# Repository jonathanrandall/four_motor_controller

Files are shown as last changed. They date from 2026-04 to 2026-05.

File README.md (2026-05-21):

# NOTE

This was originally done in kicad 9.0 and updated to kicad 10.0. Need to check the symbol for the NMOS transistor against the data sheet for the transistor in the bom file

# four_motor_controller

A 4-layer PCB motor controller for robotics applications. Drives 4 DC motors with encoder feedback using an ESP32-S3 microcontroller, 
Inlcudes:
* 4× VNH7040AYTR high-current motor drivers, which is rated for 35A, but the current is limited by the board and not the motor driver. I'm using 2oz copper on the outer layers and 1oz copper on the inner layers, so this should provide ~12A continuous current on each motor driver; and a
* MCP23017 I2C GPIO expander for direction control.

The design files are for KiCad 10.0.

The ROS2 control code used in the video is at https://github.com/jonathanrandall/new_pcb_robot

## Repository Contents

```
hardware/                   # KiCad schematic, PCB layout, and project files
  symbols/                  # Custom KiCad symbol and footprint for VNH7040AYTR
docs_and_outputs/           # BOM (JLCPCB format), Gerbers (zip), PINMAP, and datasheets
firmware/esp32_bridge/      # PlatformIO firmware project (Arduino framework, C++17)
  src/                      # main.cpp, Motor, PIDController, QuadratureEncoder,
                            #   RobotController, Mcp23017Bus, WebDashboard, PanTiltController
  include/                  # Header files
  platformio.ini            # Build configuration
```

## Important Notes

**The BOM and PINMAP in `docs_and_outputs/` may be out of date.** Always cross-reference against the schematic and PCB files before ordering parts or assembling hardware.

**The custom VNH7040AYTR symbol/footprint** (`hardware/symbols/`) must be added to your KiCad library if opening the project on a new machine.

**The firmware has not been validated on hardware.** It compiles and is provided as a starting point.

**WiFi credentials are not included.** Before building the firmware, set your SSID and password in `firmware/esp32_bridge/src/main.cpp`.

## Building the Firmware

Requires [PlatformIO](https://platformio.org/). All commands run from `firmware/esp32_bridge/`.

```bash
# Build
pio run

# Flash (USB-C, use BOOT mode if required)
pio run --target upload

# Monitor serial output (115200 baud)
pio device monitor
```

## Contributing

Contributions are welcome. If you have your own motor controller design or variant you would like to share, please add it in its own directory rather than modifying the existing files. Pull requests with bug fixes or improvements to the existing design are welcome.

## Disclaimer

This hardware design is provided as-is, with no warranty of any kind. Anyone who uses, manufactures, or builds upon these files does so entirely at their own risk. The author accepts no responsibility for any damage to property, equipment, or persons resulting from the use of this design. Always verify the design independently before fabrication or use in any application.

## Licence

The hardware design files in this repository are licensed under the
CERN Open Hardware Licence Version 2 - Permissive (CERN-OHL-P-2.0).

See the `LICENSE` file for the full licence text.

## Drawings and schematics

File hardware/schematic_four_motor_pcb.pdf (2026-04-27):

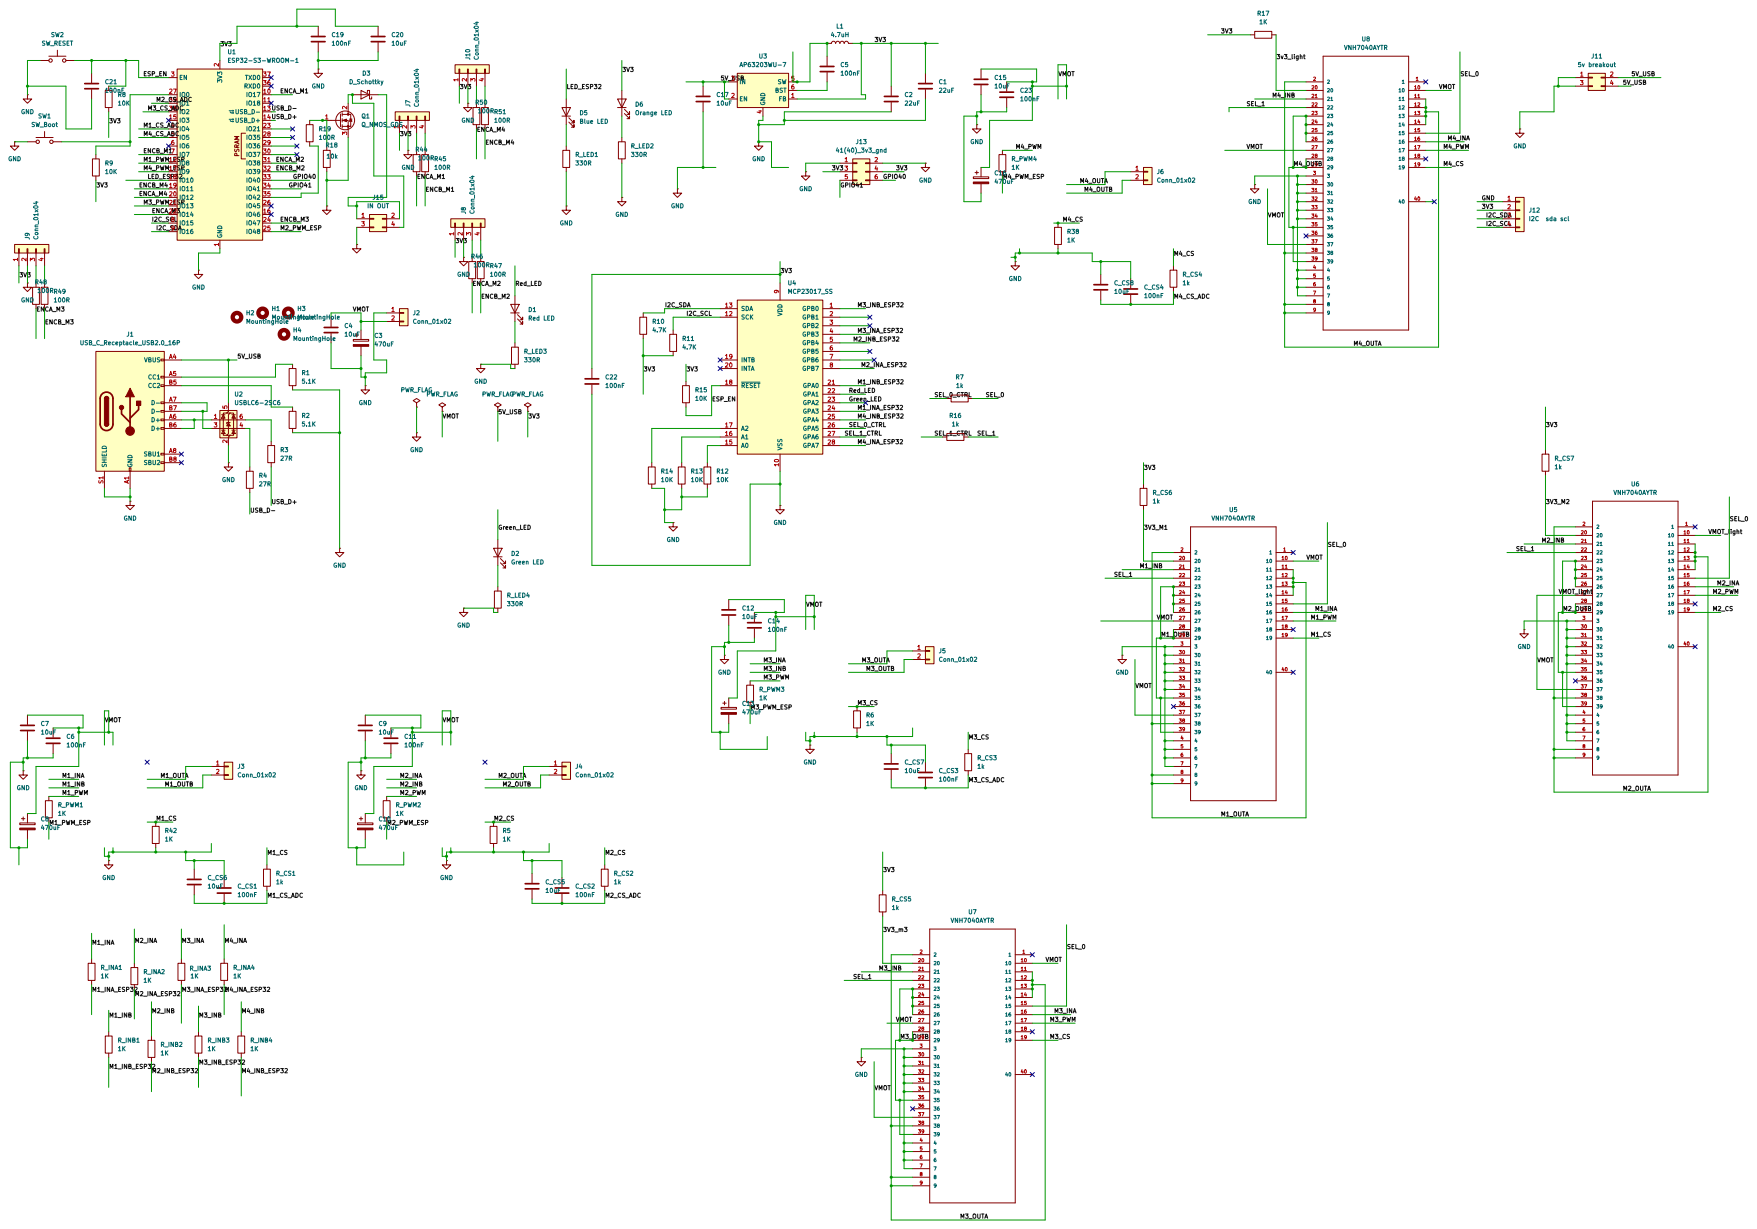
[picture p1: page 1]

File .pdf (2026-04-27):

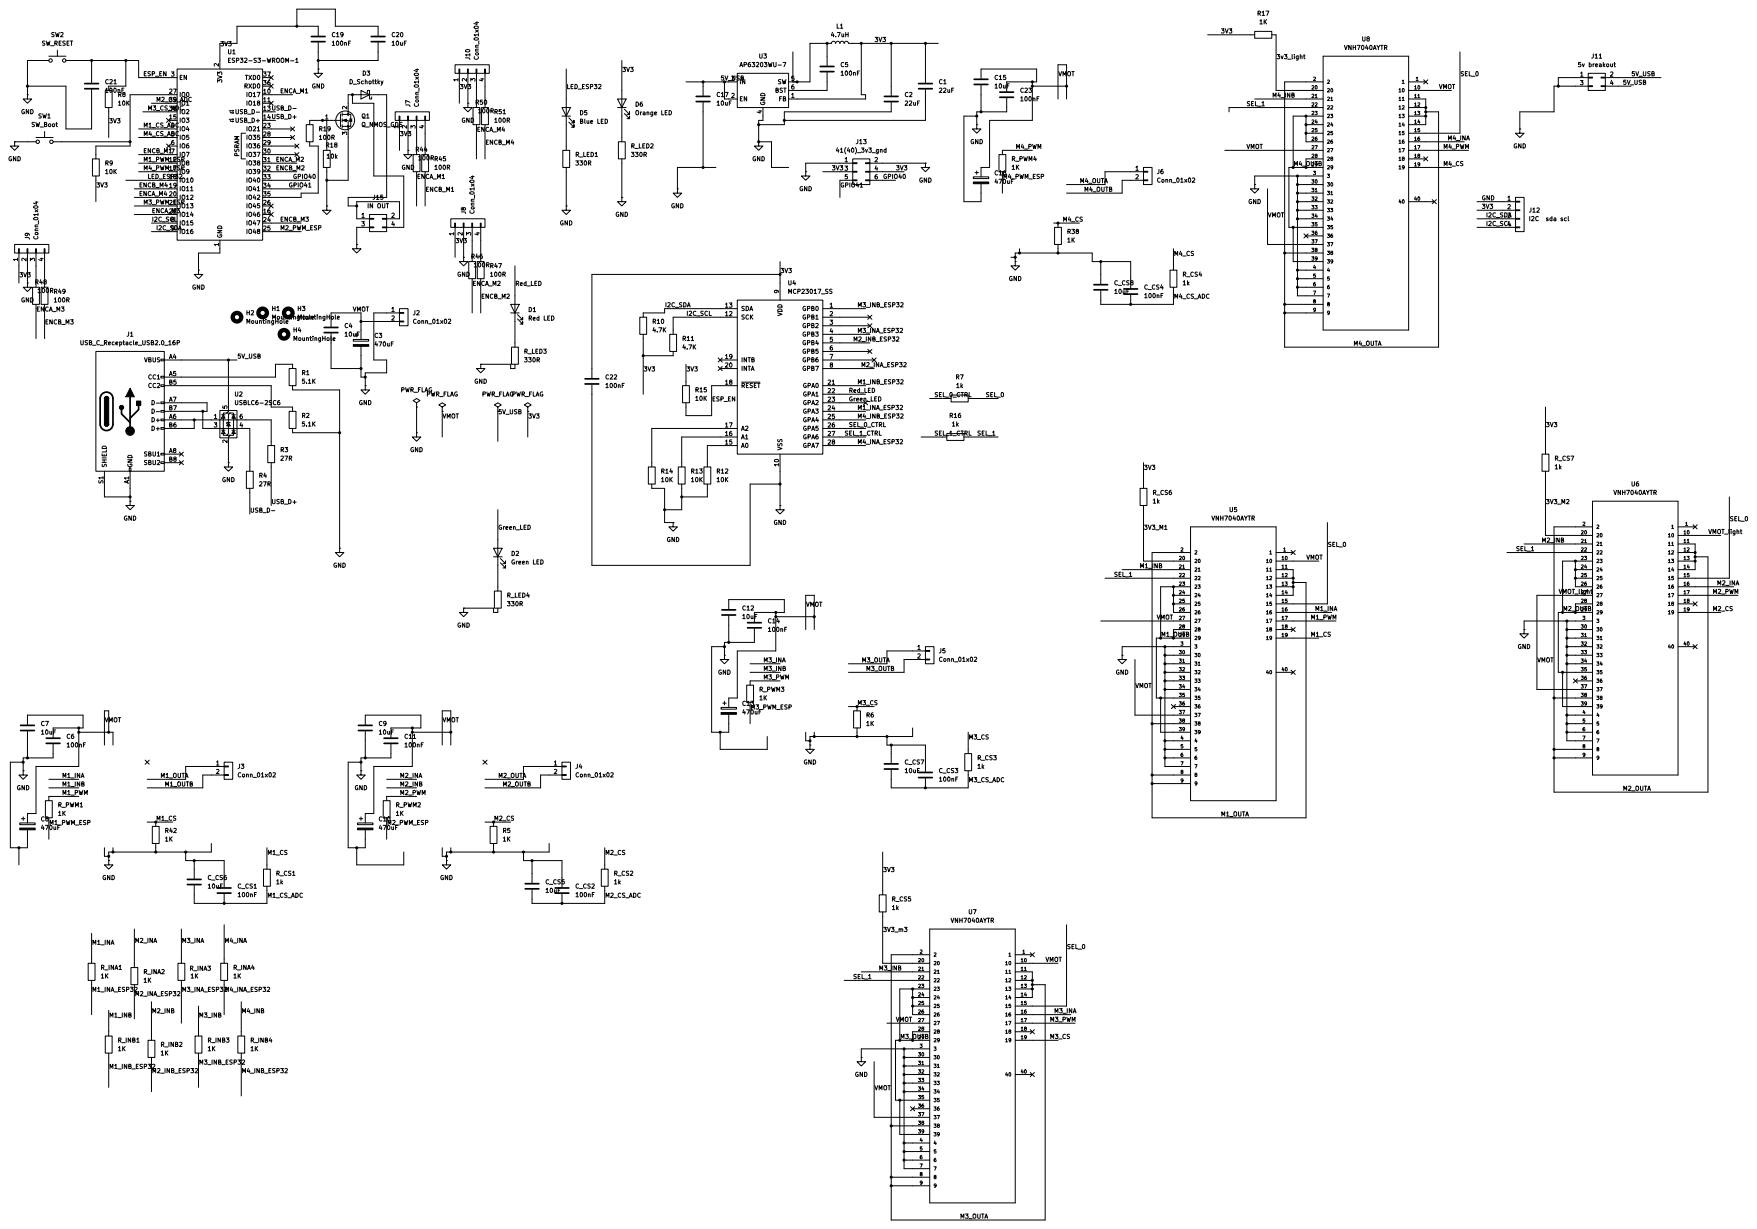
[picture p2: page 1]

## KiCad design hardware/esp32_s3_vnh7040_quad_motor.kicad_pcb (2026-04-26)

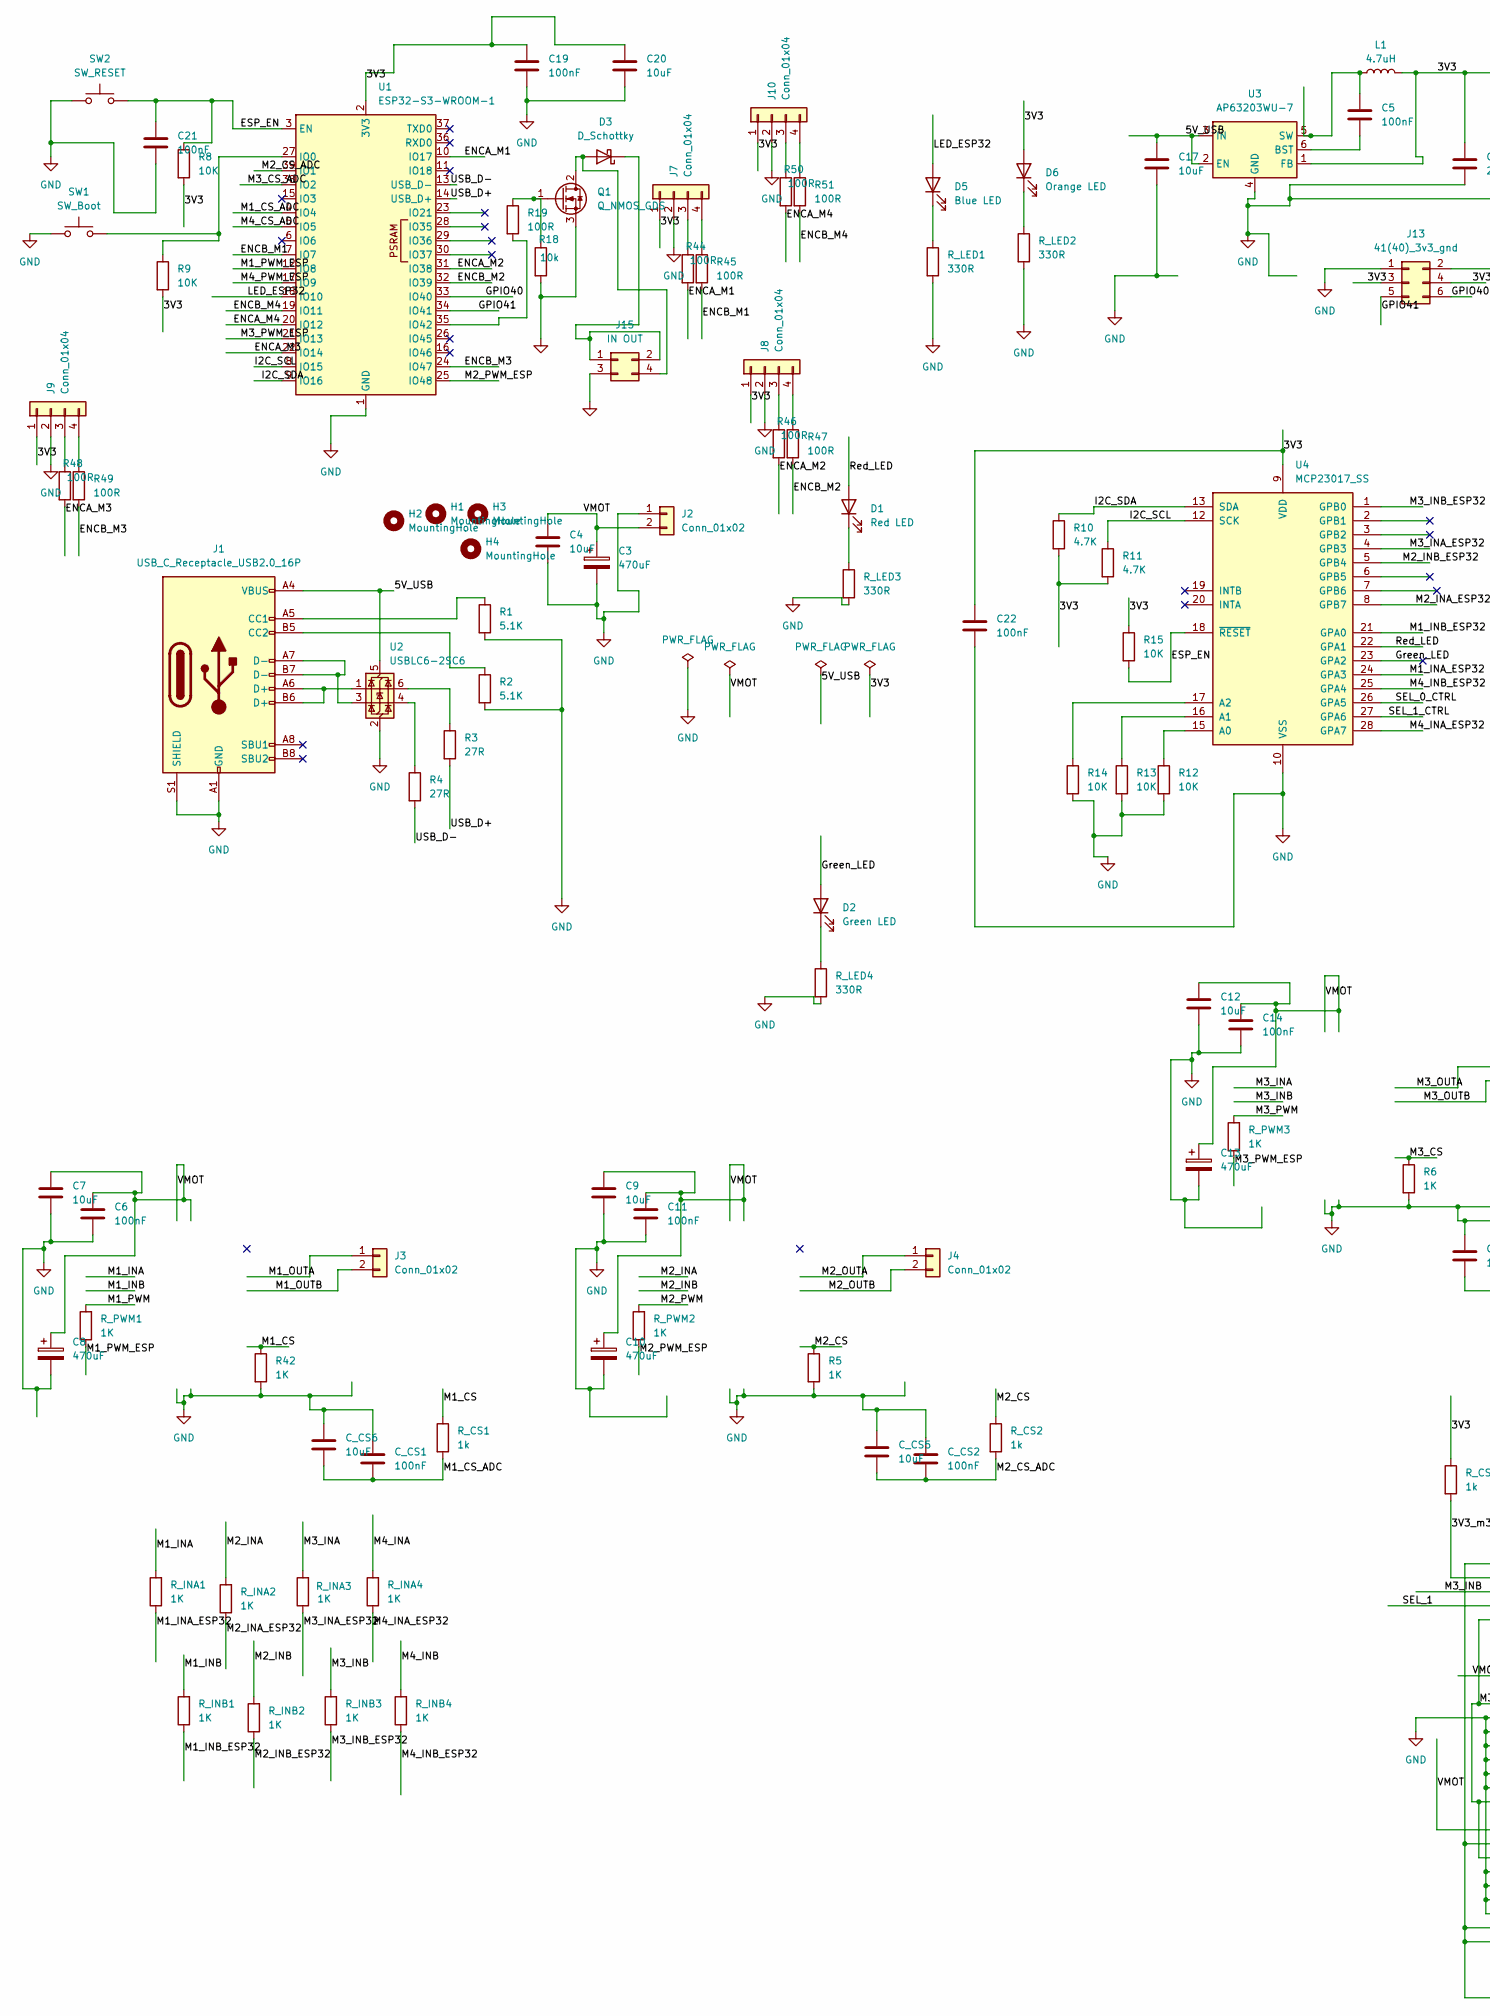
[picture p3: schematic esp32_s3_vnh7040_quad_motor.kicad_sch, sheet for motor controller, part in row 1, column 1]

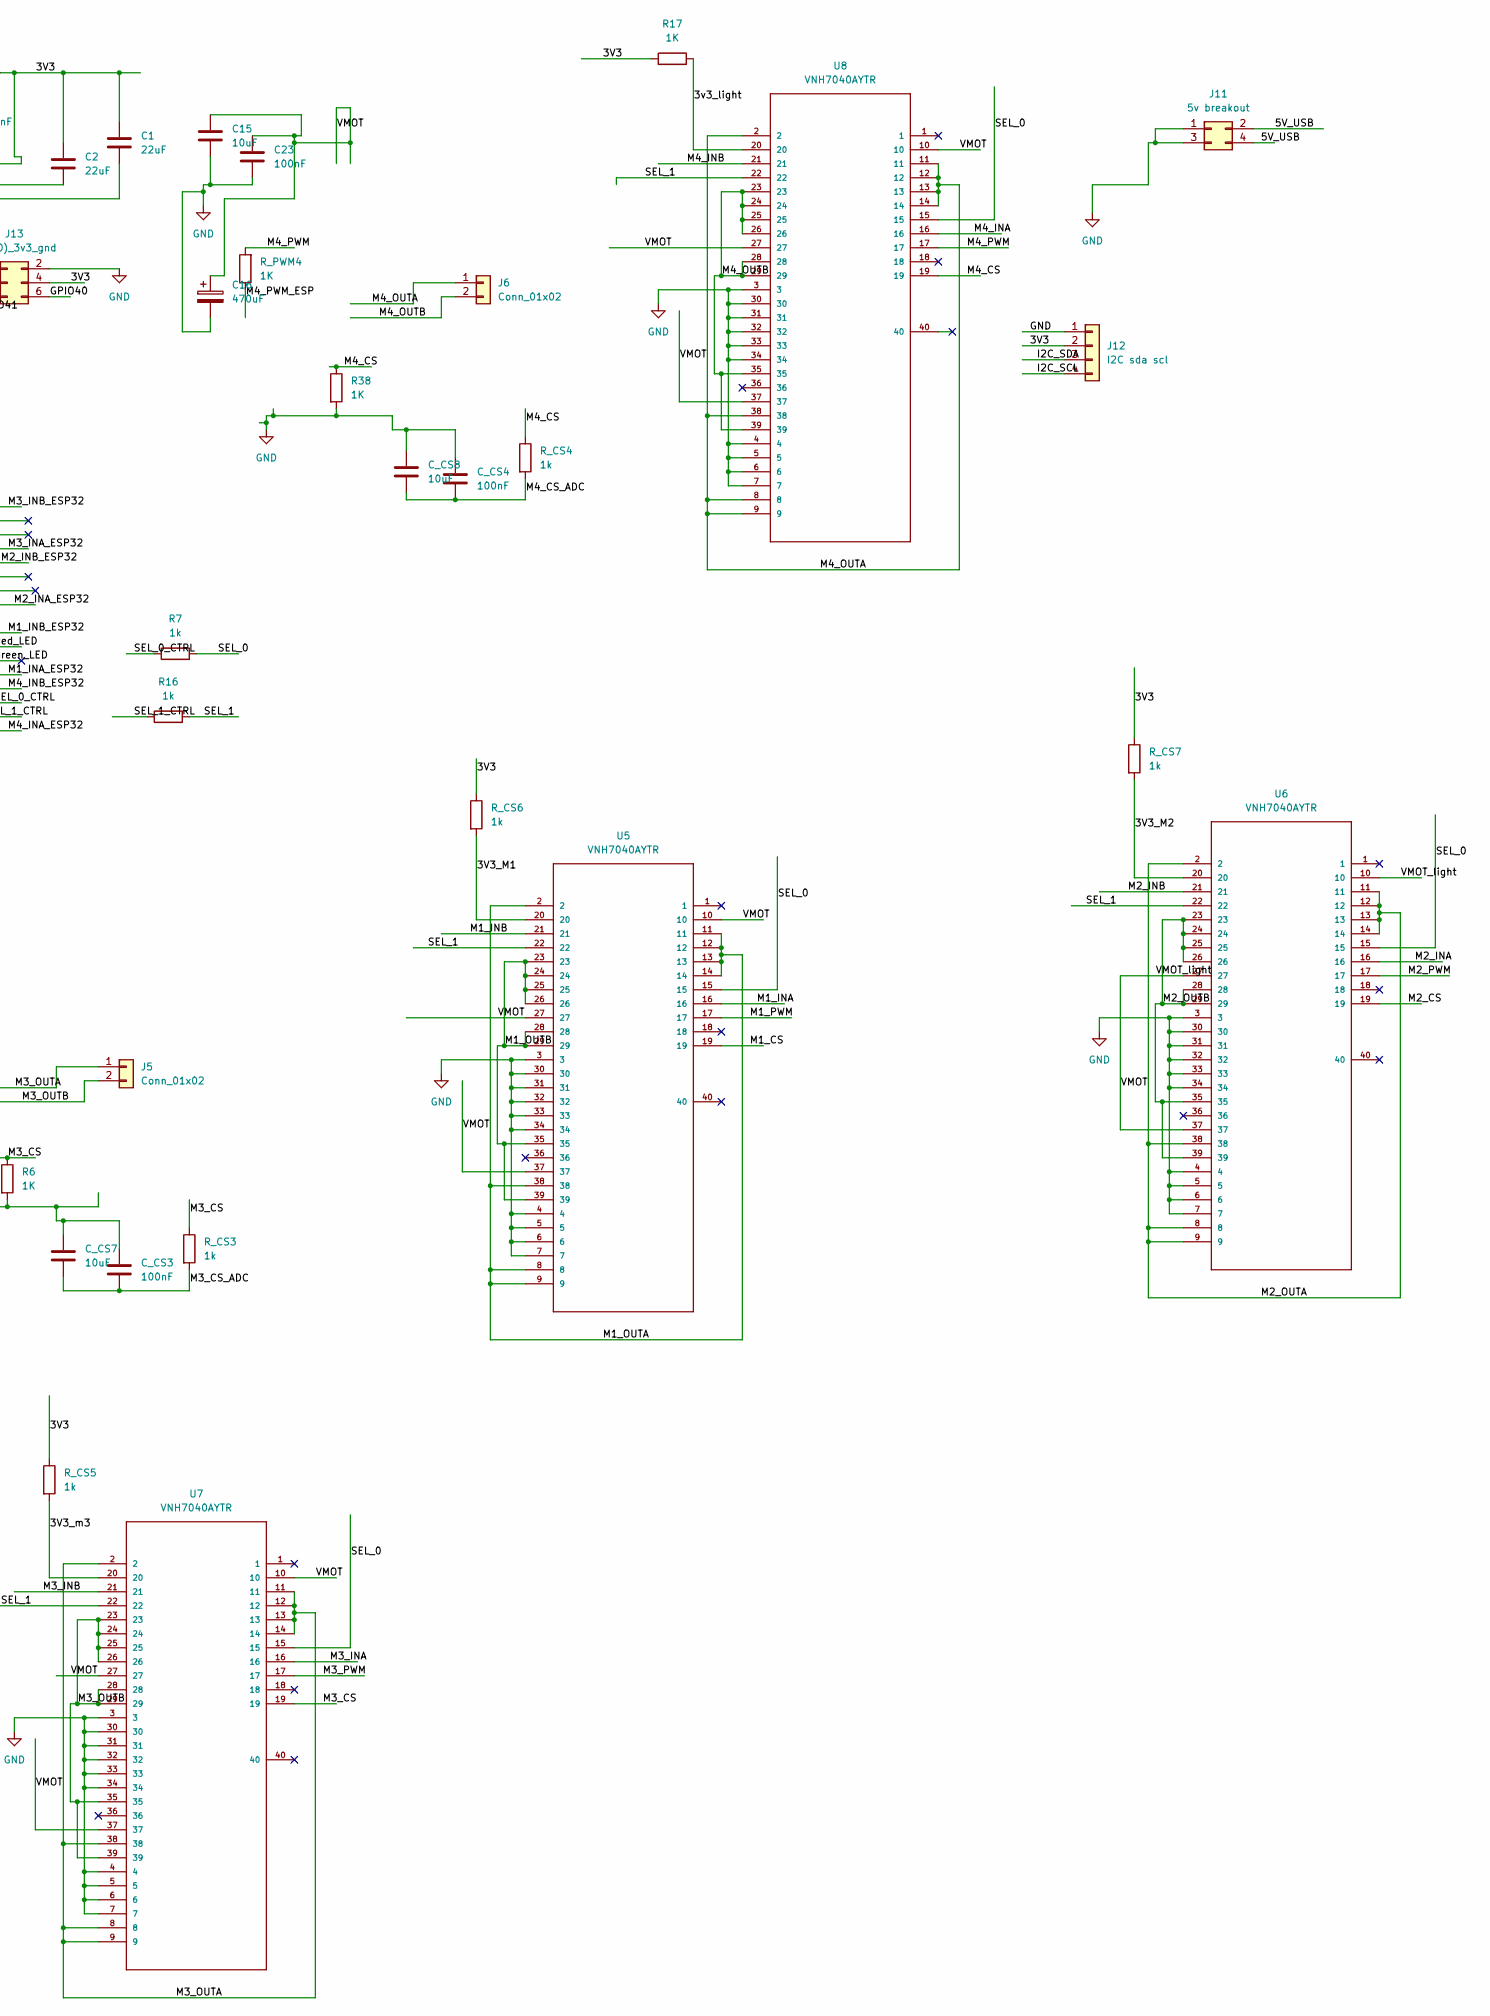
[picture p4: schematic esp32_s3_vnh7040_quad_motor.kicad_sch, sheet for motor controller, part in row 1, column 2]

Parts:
C1, C2: 22uF; C_0805_2012Metric
C3, C8, C10, C13, C16: 470uF; CP_Elec_10x10
C4, C7, C9, C12, C15: 10uF; C_1206_3216Metric
C5, C6, C11, C14, C19, C21, C22, C23: 100nF; C_0805_2012Metric
C17, C20: 10uF; C_0805_2012Metric
C_CS1, C_CS2, C_CS3, C_CS4: 100nF; C_0805_2012Metric
C_CS5, C_CS6, C_CS7, C_CS8: 10uF; C_0805_2012Metric
D1: Red LED; LED_0805_2012Metric
D2: Green LED; LED_0805_2012Metric
D3: D_Schottky; D_SMA
D5: Blue LED; LED_0805_2012Metric
D6: Orange LED; LED_0805_2012Metric
H1, H2, H3, H4: MountingHole; MountingHole_3.2mm_M3
J1: USB_C_Receptacle_USB2.0_16P; USB_C_Receptacle_HRO_TYPE-C-31-M-12
J2: Conn_01x02; AMASS_XT60PW-M_1x02_P7.20mm_Horizontal
J3, J4, J5, J6: Conn_01x02; TerminalBlock_Phoenix_MKDS-3-2-5.08_1x02_P5.08mm_Horizontal
J7, J8, J9, J10: Conn_01x04; JST_XH_B4B-XH-A_1x04_P2.50mm_Vertical
J11: 5v breakout; PinHeader_2x02_P2.54mm_Vertical
J12: I2C sda scl; PinHeader_1x04_P2.54mm_Vertical
J13: 41(40)_3v3_gnd; PinHeader_2x03_P2.54mm_Vertical
J15: IN OUT; PinHeader_2x02_P2.54mm_Vertical
L1: 4.7uH; L_7.3x7.3_H4.5
Q1: Q_NMOS_GDS; SOT-23
R1, R2: 5.1K; R_0805_2012Metric
R3, R4: 27R; R_0805_2012Metric
R5, R6, R17, R38, R42: 1K; R_0805_2012Metric
R7, R16: 1k; R_0805_2012Metric
R8, R9, R12, R13, R14, R15: 10K; R_0805_2012Metric
R10, R11: 4.7K; R_0805_2012Metric
R18: 10k; R_0805_2012Metric
R19, R44, R45, R46, R47, R48, R49, R50, R51: 100R; R_0805_2012Metric
R_CS1, R_CS2, R_CS3, R_CS4, R_CS5, R_CS6, R_CS7: 1k; R_0805_2012Metric
R_INA1, R_INA2, R_INA3, R_INA4: 1K; R_0805_2012Metric
R_INB1, R_INB2, R_INB3, R_INB4: 1K; R_0805_2012Metric
R_LED1, R_LED2, R_LED3, R_LED4: 330R; R_0805_2012Metric
R_PWM1, R_PWM2, R_PWM3, R_PWM4: 1K; R_0805_2012Metric
SW1: SW_Boot; SW_SPST_TL3342
SW2: SW_RESET; SW_SPST_TL3342
U1: ESP32-S3-WROOM-1
U2: USBLC6-2SC6; SOT-23-6
U3: AP63203WU-7; TSOT-23-6-AP63203WU
U4: MCP23017_SS; SSOP-28_5.3x10.2mm_P0.65mm
U5, U6, U7, U8: VNH7040AYTR; POWERSSO-36TP_STM_jr; MANUFACTURER_PART_NUMBER VNH7040AYTR

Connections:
/3V3: C1.1, C2.1, C19.1, C20.1, C22.1, D6.2 (A), J7.1, J8.1, J9.1, J10.1, J12.2, J13.3, J13.4, L1.2, R8.2, R9.2, R10.2, R11.2, R15.1, R17.1, R_CS5.1, R_CS6.1, R_CS7.1, U1.2 (3V3), U3.1 (FB), U4.9 (VDD)
/3V3_M1: R_CS6.2, U5.20
/3V3_M2: R_CS7.2, U6.20
/3V3_m3: R_CS5.2, U7.20
/3v3_light: R17.2, U8.20
/5V_USB: C17.1, J1.A4 (VBUS), J1.A9 (VBUS), J1.B4 (VBUS), J1.B9 (VBUS), J11.2, J11.4, U2.5 (VBUS), U3.2 (EN), U3.3 (IN)
/ENCA_M1: R44.2, U1.10 (IO17)
/ENCA_M2: R46.2, U1.31 (IO38)
/ENCA_M3: R48.2, U1.22 (IO14)
/ENCA_M4: R50.2, U1.20 (IO12)
/ENCB_M1: R45.2, U1.7 (IO7)
/ENCB_M2: R47.2, U1.32 (IO39)
/ENCB_M3: R49.2, U1.24 (IO47)
/ENCB_M4: R51.2, U1.19 (IO11)
/ESP_EN: C21.1, R8.1, R15.2, SW2.2, U1.3 (EN), U4.18 (~RESET)
/GPIO40: J13.6, U1.33 (IO40)
/GPIO41: J13.5, U1.34 (IO41)
/Green_LED: D2.2 (A), U4.23 (GPA2)
/I2C_SCL: J12.4, R11.1, U1.8 (IO15), U4.12 (SCK)
/I2C_SDA: J12.3, R10.1, U1.9 (IO16), U4.13 (SDA)
/LED_ESP32: D5.2 (A), U1.18 (IO10)
/M1_CS: R42.1, R_CS1.1, U5.19
/M1_CS_ADC: C_CS1.2, C_CS6.2, R_CS1.2, U1.4 (IO4)
/M1_INA: R_INA1.2, U5.16
/M1_INA_ESP32: R_INA1.1, U4.24 (GPA3)
/M1_INB: R_INB1.2, U5.21
/M1_INB_ESP32: R_INB1.1, U4.21 (GPA0)
/M1_OUTA: J3.1, U5.2, U5.8, U5.9, U5.11, U5.12, U5.13, U5.14, U5.38
/M1_OUTB: J3.2, U5.23, U5.24, U5.25, U5.26, U5.28, U5.29, U5.35, U5.39
/M1_PWM: R_PWM1.2, U5.17
/M1_PWM_ESP: R_PWM1.1, U1.12 (IO8)
/M2_CS: R5.1, R_CS2.1, U6.19
/M2_CS_ADC: C_CS2.2, C_CS5.2, R_CS2.2, U1.39 (IO1)
/M2_INA: R_INA2.2, U6.16
/M2_INA_ESP32: R_INA2.1, U4.8 (GPB7)
/M2_INB: R_INB2.2, U6.21
/M2_INB_ESP32: R_INB2.1, U4.5 (GPB4)
/M2_OUTA: J4.1, U6.2, U6.8, U6.9, U6.11, U6.12, U6.13, U6.14, U6.38
/M2_OUTB: J4.2, U6.23, U6.24, U6.25, U6.26, U6.28, U6.29, U6.35, U6.39
/M2_PWM: R_PWM2.2, U6.17
/M2_PWM_ESP: R_PWM2.1, U1.25 (IO48)
/M3_CS: R6.1, R_CS3.1, U7.19
/M3_CS_ADC: C_CS3.2, C_CS7.2, R_CS3.2, U1.38 (IO2)
/M3_INA: R_INA3.2, U7.16
/M3_INA_ESP32: R_INA3.1, U4.4 (GPB3)
/M3_INB: R_INB3.2, U7.21
/M3_INB_ESP32: R_INB3.1, U4.1 (GPB0)
/M3_OUTA: J5.1, U7.2, U7.8, U7.9, U7.11, U7.12, U7.13, U7.14, U7.38
/M3_OUTB: J5.2, U7.23, U7.24, U7.25, U7.26, U7.28, U7.29, U7.35, U7.39
/M3_PWM: R_PWM3.2, U7.17
/M3_PWM_ESP: R_PWM3.1, U1.21 (IO13)
/M4_CS: R38.1, R_CS4.1, U8.19
/M4_CS_ADC: C_CS4.2, C_CS8.2, R_CS4.2, U1.5 (IO5)
/M4_INA: R_INA4.2, U8.16
/M4_INA_ESP32: R_INA4.1, U4.28 (GPA7)
/M4_INB: R_INB4.2, U8.21
/M4_INB_ESP32: R_INB4.1, U4.25 (GPA4)
/M4_OUTA: J6.1, U8.2, U8.8, U8.9, U8.11, U8.12, U8.13, U8.14, U8.38
/M4_OUTB: J6.2, U8.23, U8.24, U8.25, U8.26, U8.28, U8.29, U8.35, U8.39
/M4_PWM: R_PWM4.2, U8.17
/M4_PWM_ESP: R_PWM4.1, U1.17 (IO9)
/Red_LED: D1.2 (A), U4.22 (GPA1)
/SEL_0: R7.2, U5.15, U6.15, U7.15, U8.15
/SEL_0_CTRL: R7.1, U4.26 (GPA5)
/SEL_1: R16.2, U5.22, U6.22, U7.22, U8.22
/SEL_1_CTRL: R16.1, U4.27 (GPA6)
/USB_D+: R3.2, U1.14 (USB_D+)
/USB_D-: R4.2, U1.13 (USB_D-)
/VMOT: C3.1, C4.1, C6.1, C7.1, C8.1, C9.1, C10.1, C11.1, C12.1, C13.1, C14.1, C15.1, C16.1, C23.1, J2.2, U5.10, U5.27, U5.37, U6.10, U6.27, U6.37, U7.10, U7.27, U7.37, U8.10, U8.27, U8.37
unnamed: D1.1 (K), R_LED3.1
unnamed: D2.1 (K), R_LED4.1
unnamed: D3.1 (K), J15.1, J15.2
unnamed: D5.1 (K), R_LED1.1
unnamed: D6.1 (K), R_LED2.1
unnamed: J1.A5 (CC1), R1.1
unnamed: J1.B5 (CC2), R2.1
unnamed: J1.A6 (D+), J1.B6 (D+), U2.1 (I/O1)
unnamed: J1.A7 (D-), J1.B7 (D-), U2.3 (I/O2)
unnamed: J7.3, R44.1
unnamed: J7.4, R45.1
unnamed: J8.3, R46.1
unnamed: J8.4, R47.1
unnamed: J9.3, R48.1
unnamed: J9.4, R49.1
unnamed: J10.3, R50.1
unnamed: J10.4, R51.1
unnamed: Q1.1 (G), R18.1, R19.1
unnamed: R3.1, U2.6 (I/O1)
unnamed: R4.1, U2.4 (I/O2)
unnamed: R9.1, SW1.2, U1.27 (IO0)
unnamed: R19.2, U1.35 (IO42)
unnamed: C5.2, U3.6 (BST)
unnamed: C5.1, L1.1, U3.5 (SW)
unnamed: R12.1, U4.15 (A0)
unnamed: R13.1, U4.16 (A1)
unnamed: R14.1, U4.17 (A2)

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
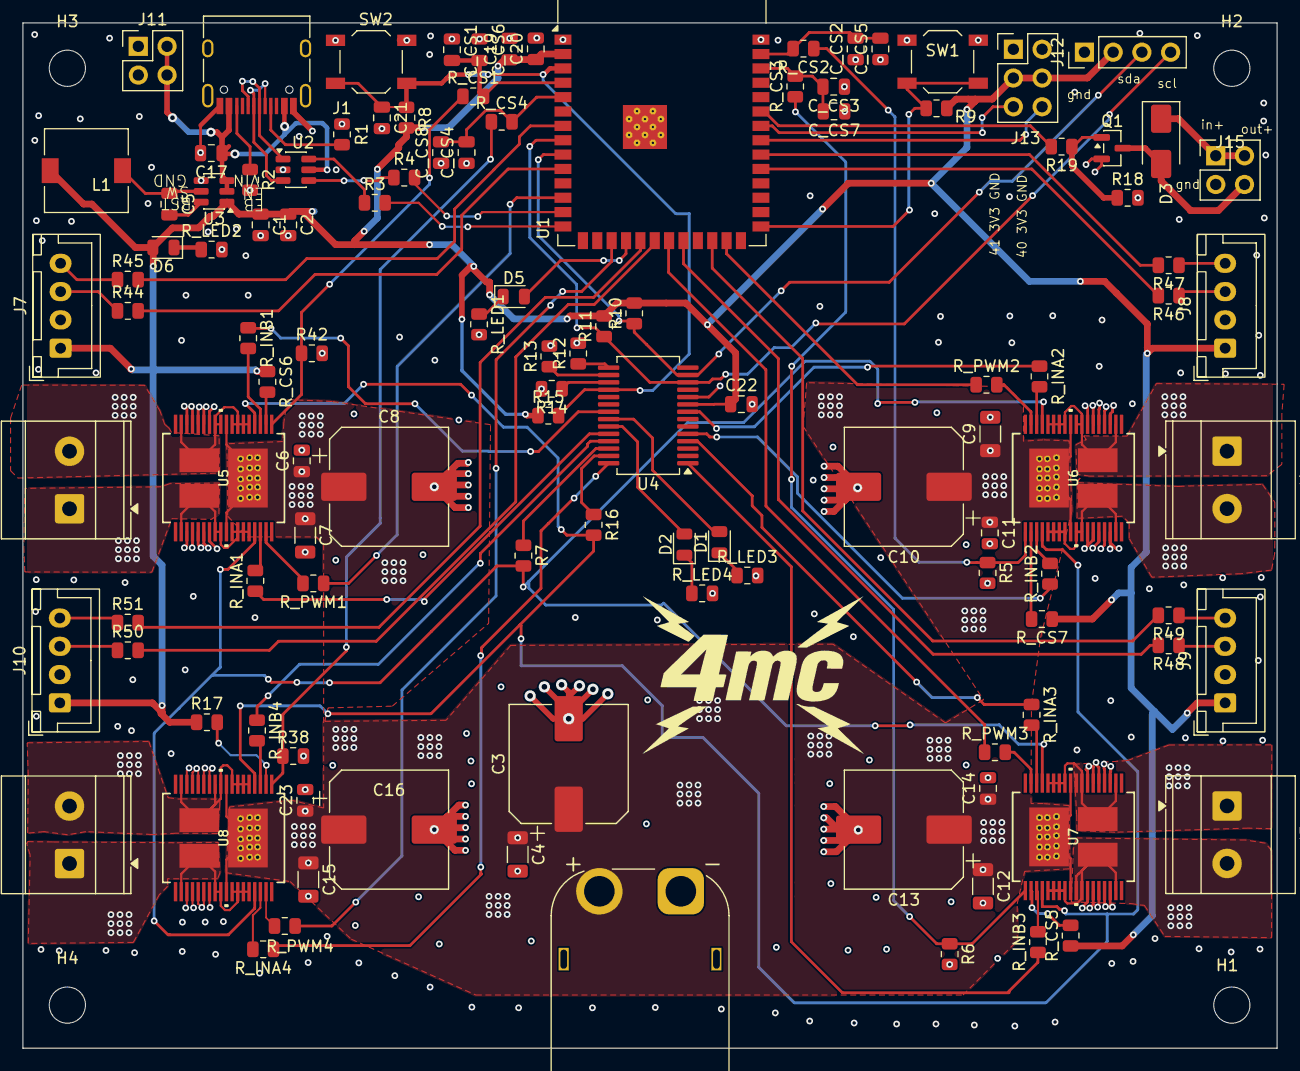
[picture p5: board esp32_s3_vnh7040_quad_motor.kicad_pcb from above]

Board: 4 copper layers, 110.8 x 90.6 mm, 117 parts (0 on the bottom side), 98 nets.

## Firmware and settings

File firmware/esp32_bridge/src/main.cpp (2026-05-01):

#include <Arduino.h>
#include <ESPmDNS.h>
#include "Mcp23017Bus.h"
#include "Motor.h"
#include "RobotController.h"
#include "PanTiltController.h"
#include "WebDashboard.h"

// ============================================================================
// CONFIGURATION - Modify these values as needed
// ============================================================================

// WiFi credentials
const char* WIFI_SSID = "WF";
const char* WIFI_PASSWORD = "";

// mDNS hostname (access via http://robot.local)
const char* MDNS_HOSTNAME = "robot";

// Robot physical parameters
const RobotParams ROBOT_PARAMS = {
    0.144f,     // wheelDiameterM: Wheel diameter in meters (90mm)
    1425.0f,     // encoderCPR: Encoder counts per revolution
    0.20f,      // wheelBaseM: Distance between left/right wheels (200mm)
    1.0f        // maxSpeedMPS: Maximum speed in m/s
};

// ============================================================================
// HARDWARE PINS
// ============================================================================

// Shared pins
constexpr int PIN_SDA = 16;
constexpr int PIN_SCL = 15;

// MCP23017 address
constexpr uint8_t MCP_ADDR = 0x20;

// MCP23017 LED pins
constexpr uint8_t MCP_RED_LED   = 1;  // GPA1
constexpr uint8_t MCP_GREEN_LED = 2;  // GPA2

// Auxiliary output
constexpr int PIN_AUX_OUT = 42;

// Motor pin configurations
// MotorPins: mcpINA, mcpINB, mcpSEL0, mcpSEL1, pwmGPIO, csAdcGPIO, encA, encB
// SEL0=GPA5(5), SEL1=GPA6(6) are shared across all four drivers
const MotorPins M1_PINS = {3,  0,  5, 6, 8,  4, 17, 7};
const MotorPins M2_PINS = {15, 12, 5, 6, 48, 1, 38, 39};  // encA/B swapped (left side)
const MotorPins M3_PINS = {11, 8,  5, 6, 13, 2, 14, 47};  // encA/B swapped (left side)
const MotorPins M4_PINS = {7,  4,  5, 6, 9,  5, 11, 12};

// Motor configuration
const MotorConfig MOTOR_CONFIG = {20000, 10, false, 0.14f, 0.0f, 3.0f};

// ============================================================================
// FREERTOS CONFIGURATION
// ============================================================================

constexpr uint32_t MOTOR_TASK_STACK_SIZE = 4096;
constexpr uint32_t MOTOR_TASK_PRIORITY = 5;
constexpr uint32_t MOTOR_UPDATE_INTERVAL_MS = 10;

constexpr uint32_t TELEMETRY_TASK_STACK_SIZE = 4096;
constexpr uint32_t TELEMETRY_TASK_PRIORITY = 2;
constexpr uint32_t TELEMETRY_UPDATE_INTERVAL_MS = 50;

constexpr uint32_t SERIAL_CMD_TASK_STACK_SIZE = 4096;
constexpr uint32_t SERIAL_CMD_TASK_PRIORITY   = 3;
constexpr uint32_t SERIAL_WATCHDOG_MS         = 1000;

// ============================================================================
// GLOBAL OBJECTS
// ============================================================================

Mcp23017Bus mcp;
Motor* motors[4];
RobotController*   robot    = nullptr;
PanTiltController* panTilt  = nullptr;
WebDashboard*      dashboard = nullptr;

// Task handles
TaskHandle_t motorTaskHandle     = nullptr;
TaskHandle_t telemetryTaskHandle = nullptr;
TaskHandle_t serialCmdTaskHandle = nullptr;

// Serial command watchdog — set to millis() on each motor command, 0 = no command received yet
volatile uint32_t lastMotorCommandMs = 0;

// Auxiliary pin state — shared with WebDashboard for telemetry
volatile bool g_auxPinHigh = false;


// Telemetry data (shared between tasks)
struct TelemetryData {
    int64_t encoderCounts[4];
    float motorCurrents[4];
    float actualSpeed;
    SemaphoreHandle_t mutex;
} telemetry;

// ============================================================================
// SERIAL COMMAND PROTOCOL (ROS2 pan/tilt diff drive interface)
//
// Messages FROM PC → ESP32 (terminated by \n):
//   "GET\n"
//       — request current state; ESP32 responds immediately with STATE message
//   "CMD,lf_vel,lr_vel,rf_vel,rr_vel,pan_pos,tilt_pos\n"
//       — set per-wheel speeds (cm/s, float) and servo positions (radians)
//   "AUX,command_name,arg\n"
//       — auxiliary commands (placeholder)
//
// Messages FROM ESP32 → PC (in response to GET):
//   "STATE,lf_pos,lr_pos,rf_pos,rr_pos,lf_vel,lr_vel,rf_vel,rr_vel,pan_pos,tilt_pos\n"
//       — encoder counts (int) and wheel velocities (cm/s, float), servo positions (radians)
//
// Wheel order: lf=FL(M3), lr=RL(M2), rf=FR(M4), rr=RR(M1)
// ============================================================================

void sendStateMessage() {
    // Encoder positions (cumulative counts, integer)
    int64_t lf_pos = robot->getEncoderCount(FRONT_LEFT);
    int64_t lr_pos = robot->getEncoderCount(REAR_LEFT);
    int64_t rf_pos = robot->getEncoderCount(FRONT_RIGHT);
    int64_t rr_pos = robot->getEncoderCount(REAR_RIGHT);

    // Wheel velocities in cm/s
    float lf_vel = robot->getFrontLeftWheelSpeed()  * 100.0f;
    float lr_vel = robot->getRearLeftWheelSpeed()   * 100.0f;
    float rf_vel = robot->getFrontRightWheelSpeed() * 100.0f;
    float rr_vel = robot->getRearRightWheelSpeed()  * 100.0f;

    float pan_pos  = panTilt ? panTilt->getPan()  : 0.0f;
    float tilt_pos = panTilt ? panTilt->getTilt() : 0.0f;

    Serial.printf("STATE,%lld,%lld,%lld,%lld,%.2f,%.2f,%.2f,%.2f,%.2f,%.2f\n",
                  lf_pos, lr_pos, rf_pos, rr_pos,
                  lf_vel, lr_vel, rf_vel, rr_vel,
                  pan_pos, tilt_pos);
}

void processSerialCommand(const String& cmd) {
    if (cmd == "GET") {
        sendStateMessage();
    }
    else if (cmd.startsWith("CMD,")) {
        float lf_vel, lr_vel, rf_vel, rr_vel, pan_pos, tilt_pos;
        if (sscanf(cmd.c_str(), "CMD,%f,%f,%f,%f,%f,%f",
                   &lf_vel, &lr_vel, &rf_vel, &rr_vel, &pan_pos, &tilt_pos) == 6) {
            // Convert cm/s to m/s, average per side for left/right differential drive
            float leftMPS  = (lf_vel + lr_vel) / 2.0f / 100.0f;
            float rightMPS = (rf_vel + rr_vel) / 2.0f / 100.0f;
            if (!robot->isEnabled()) robot->enable(true);
            robot->setWheelSpeeds(leftMPS, rightMPS);
            lastMotorCommandMs = millis();

            if (panTilt) {
                panTilt->setPan(pan_pos);
                panTilt->setTilt(tilt_pos);
            }
        }
    }
    else if (cmd.startsWith("AUX,")) {
        // Parse AUX,command_name,arg
        String rest = cmd.substring(4);
        int comma = rest.indexOf(',');
        String command_name, arg;
        if (comma >= 0) {
            command_name = rest.substring(0, comma);
            arg = rest.substring(comma + 1);
        } else {
            command_name = rest;
            arg = "";
        }
        if (command_name == "toggle") {
            static bool auxPinState = false;
            auxPinState = !auxPinState;
            g_auxPinHigh = auxPinState;
            digitalWrite(PIN_AUX_OUT, auxPinState ? HIGH : LOW);
        } else if (command_name == "fire") {
            if (!g_auxPinHigh) {
                g_auxPinHigh = true;
                digitalWrite(PIN_AUX_OUT, HIGH);
                TimerHandle_t t = xTimerCreate("auxOff", pdMS_TO_TICKS(600), pdFALSE, nullptr,
                    [](TimerHandle_t xTimer) {
                        digitalWrite(PIN_AUX_OUT, LOW);
                        g_auxPinHigh = false;
                        xTimerDelete(xTimer, 0);
                    });
                if (t) xTimerStart(t, 0);
            }
        }
    }
}

void serialCommandTask(void* parameter) {
    String line = "";
    line.reserve(64);

    while (true) {
        // Watchdog: stop motors if no motor command within timeout
        uint32_t lastCmd = lastMotorCommandMs;
        if (lastCmd > 0 && (millis() - lastCmd) > SERIAL_WATCHDOG_MS) {
            lastMotorCommandMs = 0;  // reset to prevent repeated stops
            robot->stop();
        }

        while (Serial.available()) {
            char c = (char)Serial.read();
            if (c == '\r' || c == '\n') {
                if (line.length() > 0) {
                    processSerialCommand(line);
                    line = "";
                }
            } else {
                line += c;
            }
        }

        vTaskDelay(pdMS_TO_TICKS(1));
    }
}

// ============================================================================
// FREERTOS TASKS
// ============================================================================

void motorControlTask(void* parameter) {
    TickType_t lastWakeTime = xTaskGetTickCount();
    const TickType_t interval = pdMS_TO_TICKS(MOTOR_UPDATE_INTERVAL_MS);

    Serial.println("[Motor Task] Started");

    while (true) {
        // Check individual motor faults
        bool fault = false;
        for (int i = 0; i < 4; i++) {
            if (motors[i]->hasFault()) {
                Serial.printf("[Motor Task] Motor %d FAULT (code %d)\n", i + 1, motors[i]->faultCode());
                fault = true;
            }
        }

        if (fault) {
            robot->brake();
            vTaskDelay(pdMS_TO_TICKS(1000));
            continue;
        }

        // Update encoder velocities
        for (int i = 0; i < 4; i++) {
            motors[i]->updateEncoder();
        }

        // Update robot controller (applies motor commands)
        robot->update();

        // Wait for next cycle
        vTaskDelayUntil(&lastWakeTime, interval);
    }
}

void telemetryTask(void* parameter) {
    const TickType_t interval = pdMS_TO_TICKS(TELEMETRY_UPDATE_INTERVAL_MS);

    Serial.println("[Telemetry Task] Started");

    while (true) {
        // Update telemetry data with mutex protection
        if (xSemaphoreTake(telemetry.mutex, pdMS_TO_TICKS(10)) == pdTRUE) {
            for (int i = 0; i < 4; i++) {
                telemetry.encoderCounts[i] = motors[i]->getEncoderCount();
                telemetry.motorCurrents[i] = motors[i]->readCurrentAmps();
            }
            telemetry.actualSpeed = robot->getActualLinearSpeed();
            xSemaphoreGive(telemetry.mutex);
        }

        vTaskDelay(interval);
    }
}

// ============================================================================
// SETUP AND MAIN
// ============================================================================

void setup() {
    Serial.begin(115200);
    pinMode(PIN_AUX_OUT, OUTPUT);
    digitalWrite(PIN_AUX_OUT, LOW);
    delay(1000);
    Serial.println("\n========================================");
    Serial.println("  ESP32-S3 Quad Motor Robot Controller");
    Serial.println("========================================\n");

    // Initialize telemetry mutex
    telemetry.mutex = xSemaphoreCreateMutex();

    // Initialize MCP23017
    Serial.print("Initializing MCP23017... ");
    if (!mcp.begin(PIN_SDA, PIN_SCL, MCP_ADDR)) {
        Serial.println("FAILED!");
        while (1) { delay(1000); }
    }
    Serial.println("OK");

    // Configure status LEDs (red=off, green=on to indicate ready)
    mcp.pinMode(MCP_RED_LED,   OUTPUT);
    mcp.pinMode(MCP_GREEN_LED, OUTPUT);
    mcp.writePin(MCP_RED_LED,   LOW);
    mcp.writePin(MCP_GREEN_LED, HIGH);

    // mcp.pinMode(0,   OUTPUT);
    // mcp.pinMode(3, OUTPUT);
    // mcp.writePin(0,   LOW);
    // mcp.writePin(3, HIGH);

    // Serial.println("MCP23017 initialized and LEDs configured");
    // delay(50000);
    // Serial.println("Continuing with motor initialization...");

    // Create motor objects
    motors[0] = new Motor(mcp, M1_PINS, MOTOR_CONFIG);
    motors[1] = new Motor(mcp, M2_PINS, MOTOR_CONFIG);
    motors[2] = new Motor(mcp, M3_PINS, MOTOR_CONFIG);
    motors[3] = new Motor(mcp, M4_PINS, MOTOR_CONFIG);

    // Initialize each motor
    for (int i = 0; i < 4; i++) {
        Serial.printf("Initializing Motor %d... ", i + 1);
        if (!motors[i]->begin(static_cast<pcnt_unit_t>(i))) {
            Serial.println("FAILED!");
            while (1) { delay(1000); }
        }
        Serial.println("OK");
    }

    // Create robot controller
    robot = new RobotController(motors, ROBOT_PARAMS, &mcp, MCP_RED_LED, MCP_GREEN_LED);
    robot->begin();
    Serial.println("Robot controller initialized");

    // Initialize pan/tilt controller (PCA9685 on same I2C bus)
    panTilt = new PanTiltController();
    if (!panTilt->begin()) {
        Serial.println("Pan/tilt init failed — continuing without it");
        delete panTilt;
        panTilt = nullptr;
    }

    // Print robot parameters
    Serial.println("\nRobot Parameters:");
    Serial.printf("  Wheel diameter: %.3f m\n", ROBOT_PARAMS.wheelDiameterM);
    Serial.printf("  Encoder CPR: %.0f counts/rev\n", ROBOT_PARAMS.encoderCPR);
    Serial.printf("  Wheel base: %.3f m\n", ROBOT_PARAMS.wheelBaseM);
    Serial.printf("  Max speed: %.2f m/s\n", ROBOT_PARAMS.maxSpeedMPS);

    // Connect to WiFi and start web server
    Serial.println("\nConnecting to WiFi...");
    dashboard = new WebDashboard(*robot, panTilt);
    if (!dashboard->begin(WIFI_SSID, WIFI_PASSWORD)) {
        Serial.println("WiFi failed - continuing without web dashboard");
    } else {
        // Start mDNS responder
        if (MDNS.begin(MDNS_HOSTNAME)) {
            MDNS.addService("http", "tcp", 80);
            Serial.printf("mDNS started: http://%s.local\n", MDNS_HOSTNAME);
        } else {
            Serial.println("mDNS failed to start");
        }

        Serial.println("\n========================================");
        Serial.print("  Dashboard: http://");
        Serial.println(dashboard->getIP());
        Serial.println("========================================\n");
    }

    // ---- TEST: Drive forward for 5 seconds ----
    // Serial.println("\n[TEST] Driving forward at 0.3 m/s for 5 seconds...");
    // bool prevPIDState = robot->isPIDEnabled();
    // bool tmp = robot->isEnabled();
    // robot->enable(true);
    // robot->forward(0.3f);
    
    // robot->enablePID(false);
    // uint32_t testStart = millis();
    // while (millis() - testStart < 5000) {
    //     for (int i = 0; i < 4; i++) motors[i]->updateEncoder();
    //     robot->update();
    //     delay(10);
    // }
    // robot->brake();
    // robot->enablePID(prevPIDState);
    // robot->enable(tmp);
    // Serial.println("[TEST] Done.\n");
    // ---- END TEST ----

    // Create FreeRTOS tasks
    Serial.println("Starting FreeRTOS tasks...");

    xTaskCreatePinnedToCore(
        motorControlTask,
        "MotorControl",
        MOTOR_TASK_STACK_SIZE,
        nullptr,
        MOTOR_TASK_PRIORITY,
        &motorTaskHandle,
        1  // Run on core 1
    );

    xTaskCreatePinnedToCore(
        telemetryTask,
        "Telemetry",
        TELEMETRY_TASK_STACK_SIZE,
        nullptr,
        TELEMETRY_TASK_PRIORITY,
        &telemetryTaskHandle,
        0  // Run on core 0
    );

    xTaskCreatePinnedToCore(
        serialCommandTask,
        "SerialCmd",
        SERIAL_CMD_TASK_STACK_SIZE,
        nullptr,
        SERIAL_CMD_TASK_PRIORITY,
        &serialCmdTaskHandle,
        0  // Run on core 0
    );

    Serial.println("System ready!\n");
}

void loop() {
    // Main loop is mostly idle - work is done in FreeRTOS tasks
    // Just print status periodically

    static uint32_t lastStatusTime = 0;
    uint32_t now = millis();

    // Status print disabled — Serial is used for ROS2 serial protocol
    (void)lastStatusTime;
    (void)now;

    delay(100);
}

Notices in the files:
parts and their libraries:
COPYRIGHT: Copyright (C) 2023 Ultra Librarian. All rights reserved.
